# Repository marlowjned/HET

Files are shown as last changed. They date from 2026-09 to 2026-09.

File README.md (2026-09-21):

# HET — Hall Effect Thruster simulation

Simulating the magnetic circuit (and eventually more) of the BPL-700 Hall
Effect Thruster, from first-pass sizing through real-CAD magnetostatic FEM
solves. Two independent geometry/FEM toolchains exist side by side because
the first one (MATLAB) hit a real geometry-kernel limitation partway
through; rather than being redundant, the second (Gmsh+GetDP) is the one
that's currently ahead and validated. This file is a map of the repo, not a
status report — each subfolder's own README/notes carry current status.

Material properties used anywhere in the project, with sources and a
per-value confidence rating, are collected in **`MATERIALS.md`**.

## Layout

- **`sizing/`** — `basic_het_sizing.py`: zero-CAD, textbook top-level
  sizing (Goebel & Katz scaling laws) — discharge current, channel
  geometry, thrust/Isp/efficiency, and a Larmor-radius magnetization
  check, from power/voltage targets. Upstream of everything else: this is
  where target channel dimensions and required B-field would come from if
  a new design point is needed, rather than the current placeholder
  numbers used downstream.
- **`matlab/`** — first magnetostatics pipeline: idealized parametric
  coil model (working), plus a real-CAD (Onshape STEP) import and
  placement pipeline (working). Blocked partway through multi-material
  assignment by a `fegeometry.union()` limitation on 5 of 9 real
  part-to-part interfaces (sliver/degenerate faces) — see
  `matlab/README.md` for the full diagnosis. Still the source of the real
  per-part transforms and material list used by the other pipeline.
- **`gmsh_getdp/`** — second, independent magnetostatics pipeline (Gmsh
  for geometry/meshing, GetDP for the FEM solve, both compiled native
  code) built specifically because it doesn't hit MATLAB's union
  blocker. Currently the most complete part of the project: validated
  against an analytic solenoid check, solves the full real assembly,
  and has run a center/outer current-ratio sweep. See
  `gmsh_getdp/README.md` for status/results and `gmsh_getdp/HOW_IT_WORKS.md`
  for the physics-to-code walkthrough (read that one to understand *why*
  any given step exists, not just what it does).
- **`thermal/`** — steady-state thermal model of the magnet circuit
  running on its own (coil dissipation only, no plasma load), in
  vacuum with radiation as the only heat path. Takes its radiating
  envelope from the `gmsh_getdp/` mesh and its winding design from
  that pipeline's operating point. Answers the "is anything getting
  hot before we add any other physics" question: no, with ~3x current
  margin to the first material limit. See `thermal/README.md`.
- **`tools/`** — gitignored, machine-local third-party binaries (the
  Windows GetDP executable). Not checked in; see `gmsh_getdp/README.md`
  "Setup" for how to repopulate it on a new machine.
- **`onshape/`** — HMAC API-key auth layer + caching STEP pull for a
  parametrized Onshape CAD document, keyed on all 5 real Configuration
  parameters (`emag_height`, `inner/outer_coil_id/od`). Auth and the
  multi-param STEP export are both validated end-to-end and wired
  directly into `gmsh_getdp/assembly/build_assembly.py`'s geometry
  ingestion. See `onshape/README.md`.

## How the pieces fit together

`sizing/` → target channel geometry and B-field (not yet actually wired
into the CAD dimensions below — the CAD is the existing real BPL-700
hardware, not a from-scratch design derived from this script). CAD
geometry now comes directly from a whole-assembly Onshape STEP export
(`onshape/cache.py` → `gmsh_getdp/assembly/build_assembly.py`), which
recovers Onshape's own real per-occurrence placement and part names
directly — the `matlab/` pipeline's hand-extracted per-part transforms
are no longer used by `gmsh_getdp/`. Material list (which parts are iron
vs. inert) originates in `matlab/README.md`'s diagnosis but is
re-confirmed against the real STEP body names in
`gmsh_getdp/assembly/build_assembly.py`. From here, active development is
in `gmsh_getdp/` — `matlab/` is not being advanced further unless the
union blocker gets resolved on the Onshape side.

## Current overall status

- Real-geometry magnetostatic B-field solve: **working**, in
  `gmsh_getdp/assembly/`, sourced from a parametrized whole-assembly
  Onshape STEP export (all 5 geometry params) rather than a fixed
  hardcoded geometry. Nonlinear iron (ASTM A36, modelled with an AISI 1008 proxy B-H curve,
  replacing the old linear `mur_iron=1000` placeholder) is implemented
  and **converging** — see `gmsh_getdp/README.md` "Nonlinear iron
  (B-H curve)". Winding excitation is no longer a placeholder: it's a
  real winding design (260/165 turns at 1.30 A) sized to the ~300 G
  channel-exit target, which is also what made the nonlinear solve
  tractable, since the old 5 A placeholder drove the iron past
  saturation. The magnet circuit needs ~3.8 V at 1.30 A, ~5.8 W.
- Top-level thruster sizing (power/thrust/Isp from design targets):
  **working**, standalone, in `sizing/`.
- Magnets-only thermal: **working**, in `thermal/` — 64 °C at the
  design point, first material limit (wire insulation) at ~2.4× design
  current. Plasma-loaded thermal is not modelled.
- Spacer-height geometry sweep: **done** —
  `gmsh_getdp/assembly/emag_sweep.py` drives Onshape → mesh → linear
  solve across `emag_height` (spacer 0–0.875 in) × inner core diameter;
  `sizing/winding_design.py` turns each result into a winding, current,
  voltage, power and temperature. Write-up with figures, every coil
  geometry and the power-supply requirements:
  **`EMAG_REPORT.pdf`** (rebuild with
  `python report/make_report.py`, which writes `EMAG_REPORT.pdf`).
- Not yet started: wiring `sizing/`'s targets into the CAD dimensions,
  electric-field/plasma simulation, electron
  trajectory/stability, plasma-loaded thermal, and structural/force
  analysis.

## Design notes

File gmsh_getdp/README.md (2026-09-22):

# HET B-field simulation: Gmsh + GetDP pipeline

A second, independent magnetostatics pipeline for the same BPL-700
geometry as `../matlab/`, built after MATLAB's `fegeometry.union()` proved
unable to cleanly union 5 of the assembly's 9 real touching interfaces
(sliver faces, unmeshable at any resolution -- see `../matlab/README.md`,
"Blocker hit at step 1"). Both mesh generation (Gmsh) and the FEM
assembly/solve (GetDP) are compiled native code -- Python here is only
orchestration (build geometry, write the mesh, shell out to `getdp.exe`,
read results back), not the numerical engine.

## Status

- **Toy validation**: done and passing. `toy_test/` builds a single
  parametric solenoid coil (same dimensions as
  `../matlab/het_solenoid_bfield.m`'s center coil) and solves it with
  GetDP's magnetic-vector-potential formulation. Result: 27.63 mT on-axis
  at coil center, vs. 28.02 mT from the exact analytic on-axis integral
  for a finite thick solenoid (1.4% agreement) -- confirms the mesh,
  formulation, and gauge are all correct before trusting them on the real
  CAD. Run `python check_toy.py` after the solve: it asserts the
  comparison rather than leaving it as a number quoted here, which is what
  let a real error hide for months -- see "The A_cross bug" below.
- **Real assembly**: done and solving, now sourced from a **whole-assembly
  Onshape STEP export** (via `../onshape/cache.py`) rather than the
  original per-part-STEP + hardcoded-transform approach. `assembly/
  build_assembly.py` imports all 14 named bodies directly (7 iron + 5 real
  coil solids + chamber + chamber_spacer), fuses the iron bodies
  **incrementally** into one solid, keeps the 5 coil solids as real
  windings (no more `occ.addCylinder`/`occ.cut` primitive construction),
  meshes, and solves. **All real touching interfaces mesh cleanly** (vs.
  MATLAB's 4/9) -- see "The geometry win" below. All 5 real Onshape
  Configuration parameters (`emag_height`, `inner/outer_coil_id/od`) now
  drive this pull -- see `../onshape/cache.py`'s docstring for why (the
  soft-iron core's diameter IS the coil ID it wraps, so there's no
  separate core-diameter parameter). `chamber_spacer` is iron (confirmed
  2026-09-21: the same A36 as the plates; `--exclude-chamber-spacer`
  still tests the inert case).
- **Center/outer current-ratio sweep**: done at the old geometry and the
  old linear-iron material (pole names `center_solenoid`/`outer_solenoid`,
  since renamed to `inner_coil`/`outer_coil` -- `current_sweep.py` itself
  is updated for the rename, but hasn't been re-run against the new
  whole-assembly geometry, and its channel statistics predate the ROI
  correction below). Found the most radial (E x B - correct) channel
  field at `I_center = I_outer` -- see "Current ratio sweep" below. **Its
  2-basis-solve superposition trick assumes a linear material**, which
  looked fatal once Iron became nonlinear -- but at the real ~300 G design
  point the iron peaks at 1.023 T, below the B-H knee, so it behaves
  near-linearly and the trick is roughly valid there. Note this got
  *weaker* when the material became A36-proxy rather than the old generic
  curve: 1.023 T is past that curve's peak-permeability point (0.865 T),
  so superposition is now an approximation rather than near-exact.
  Re-check it if a design point pushes the iron further.
- **Materials**: nonlinear iron (ASTM A36, run on a proxy B-H curve) replaces
  the `mur_iron = 1000` linear placeholder, and **converges** -- 33
  Picard iterations, 68 min wall, 806 MB peak. See "Nonlinear iron
  (B-H curve)" below for how the excitation, not the method, was what
  made that work. The iteration count roughly tripled when the material
  went from the generic curve to the A36 proxy: the design's peak iron
  field sits past that curve's permeability peak, where Picard contracts
  slowly. Worth budgeting for in the geometry sweep.
- **Excitation**: 1.30 A per coil (inner 260 t, outer 165 t) -- a real
  winding design sized to the ~300 G channel-exit target, not the old
  inherited 300/200 at 5 A. Measured 288.6 G at the exit plane at 1.25 A,
  hence 1.30 A for 300 G. See "Operating point" below.
- **Channel ROI**: the channel bounds in `assembly_params.txt` are the
  real plasma cavity between the chamber's ceramic walls, not the chamber
  part's bounding annulus (which contained iron). See "Channel ROI" below.
- **chamber**: deliberately excluded from the solid model (see
  `assembly/build_assembly.py` docstring) -- magnetically inert (mu_r ~=
  1, same as air), so omitting it doesn't affect the B-field solve.
  **injector** isn't present in the whole-assembly STEP export at all
  (confirmed) -- harmless, it was already excluded for the same reason.

## Setup

```
pip install gmsh meshio pyvista        # geometry/meshing API, VTK export, VTK-based slicing (all C++ core underneath)
# GetDP: download the Windows binary from https://getdp.info/ (bin/Windows/getdp-3.5.0-Windows64c.zip)
# and unzip it -- this repo expects it at ../tools/getdp-3.5.0-Windows64/getdp.exe
# (../tools/ is gitignored; not checked in)
```

## Running

```
cd toy_test
python build_toy.py
"../../tools/getdp-3.5.0-Windows64/getdp.exe" magnetostatics_toy.pro -msh toy.msh -solve Res_a -pos Map_b
python check_toy.py                             # asserts the FEM against the exact analytic field; exits non-zero on failure

cd ../assembly
python build_assembly.py                       # writes assembly.msh + assembly_regions_generated.pro + assembly_params.txt
"../../tools/getdp-3.5.0-Windows64/getdp.exe" magnetostatics_assembly.pro -msh assembly.msh -solve Res_a -pos Map_b
python post_process.py                          # writes solve_summary.txt + cross_section.png (quick static check)
python export_vtk.py                             # writes assembly_field.vtu + iron_field.vtu (standard VTK) -- run before the viewer below
python cross_section_viewer.py                  # interactive angle-sweep viewer (opens a window), reads assembly_field.vtu
```

## The geometry win

MATLAB's `union()` broke on 5 of 9 real touching interfaces: all 3 of
chamber's contacts (hard failure, degenerate triangles) and 2 of the 4
outer-pole-to-top-plate mates (sliver faces, unmeshable). Gmsh/OCC's
fuzzy-tolerance boolean kernel (`Geometry.ToleranceBoolean`) fused all 7
real iron parts (top plate, bottom plate, center pole, 4 outer poles) into
a single solid **on the first try**, including the exact
outer_solenoid_2/_7 <-> top_plate mates that broke MATLAB. This is the
main validation that switching toolchains actually fixes the root
problem, not just relocates it.

## Result file formats

- **`assembly.msh`** -- the mesh (nodes, elements, physical-group region
  tags). Gmsh legacy ASCII v2.2. No field data.
- **`b_assembly.pos`, `b_iron.pos`** -- GetDP's native output (Gmsh's
  `.pos` ASCII post-processing view format): one `VS(...){...}` line per
  tetrahedron, its 4 corner coordinates and constant field value. Plain
  text, large (~200MB for the full assembly).
- **`assembly_field.vtu`, `iron_field.vtu`** (`export_vtk.py`) -- the same
  field data as standard VTK (XML/binary, `UnstructuredGrid`), for
  ParaView or any other VTK-standard consumer -- the interoperable format
  if this ever gets layered against other simulation tools. Built via
  `meshio` directly from the `.pos` element data (each tet keeps its own
  4 corner points rather than being deduplicated against a shared mesh --
  see `export_vtk.py`'s docstring for why: **`gmsh.view.write(tag,
  "*.vtk")` looked like it worked (no error) but silently wrote a
  non-standard format** -- no `# vtk DataFile` header, none of the
  expected `POINTS`/`CELLS` sections -- so don't reach for it as a
  shortcut here). Verified by a full round-trip read: peak `|B|` in the
  `.vtu` matches the known `.pos` value (9.671343399912887 T) exactly.
- `post_process.py` still reads `.pos` directly via `pos_utils.py` (its
  own quick static check, unchanged). `cross_section_viewer.py` now reads
  `assembly_field.vtu` via `pyvista` instead -- see "Known limitations"
  below for why that's a real accuracy improvement, not just a format
  swap, and note it means `export_vtk.py` must be run before the viewer.

## Current ratio sweep

`assembly/current_sweep.py` sweeps the center-solenoid / outer-solenoid
current ratio and finds which one makes the discharge-channel field most
radial (perpendicular to the thruster centerline) -- the standard Hall
thruster requirement for E x B electron confinement.

**Key physics shortcut**: with the linear `mur_iron = 1000` placeholder
(no B-H saturation), the magnetostatics problem is linear in the winding
currents, so solutions superpose. The script solves GetDP only twice --
once with 1 A in the center winding alone, once with 1 A in each outer
winding alone -- caches both per-element channel fields to
`channel_basis.npz`, then evaluates `B(x) = I_center * B_center_unit(x) +
I_outer * B_outer_unit(x)` for any current pair instantly in Python (no
remeshing or re-solving). Use `--skip-solve` to re-sweep or re-plot from
the cached basis without paying for the two GetDP solves again.

**Result** (`sweep_results.csv`, `sweep_ratio.png`; 25 ratios from 0.4 to
2.5, `I_outer` fixed at the reference 5 A/coil): the channel field is most
radial -- lowest volume-weighted axial fraction, `mean(|B_y|/|B|) =
0.4848` -- at **`I_center / I_outer = 1.0`**, i.e. equal current in the
center and each outer coil (`I_center = I_outer = 5 A`). This happens to
coincide with the placeholder excitation already used for the base solve
(`center 300t/5A, outer 200t/5A`) -- not by design, since the turns
differ 300 vs. 200 per coil, but the ratio metric is fairly flat near its
minimum (axial fraction only rises from 0.485 to ~0.54 across the whole
swept range), so this isn't a sharp optimum. At that point:

- channel `|B|` mean = 80.6 mT, median = 8.5 mT, p90 = 33.3 mT (the mean
  is pulled up by a small high-field volume near the pole faces; the
  median is more representative of the bulk channel field).
- to hit a different target channel field while keeping the field
  direction optimal, scale **both** currents together by
  `target / 80.6 mT`, keeping the 1:1 ratio fixed.

**Those three magnitude numbers are stale** -- they were computed with
the old channel mask (the chamber part's bounding annulus, which
included iron; see "Channel ROI" above), so they average pole-face field
into the channel and the spread between mean/median/p90 is largely that
contamination rather than real structure. Over the corrected plasma
cavity the field is far more uniform and almost purely radial (97.7%).
The *ratio* result is unaffected -- that metric is scale-invariant and
the contamination was symmetric across ratios -- but don't use the mT
figures above to size current; use "Operating point" instead.

This is a field-direction optimum only -- it says nothing about the
field *magnitude* needed for a real operating point (that depends on
electron Larmor radius / discharge voltage requirements, not modeled
here), and the underlying solve is the linear/no-saturation placeholder
-- though see "Nonlinear iron" above for why superposition turns out to
be legitimate at the real design point anyway.

## Spacer-height sweep (`emag_sweep.py`)

Sizes the `chamber_spacer`. Full write-up, figures and every coil geometry:
**`../EMAG_REPORT.pdf`**. Geometry facts it rests on,
measured from the STEP exports:

- **spacer = emag_height - 1.125 in.** The chamber and top plate never
  move; emag_height moves only the bottom plate. At 1.125 in Onshape drops
  the spacer body entirely (`build_assembly.py` accepts that).
- The chamber bore and spacer bore are both the inner coil's OD
  (r 17.46 mm), so the inner winding can only grow inward by thinning the
  core (`inner_coil_id`). The pole cap stays 1.375 in regardless.

Grid: emag_height 1.125-2.0 in (spacer 0-0.875 in, 0.125 steps) x inner
core 1.000/0.875/0.750 in, plus one outer-OD 1.625 in check -- 25 points.
**Linear iron** (mu_r 1500): +1.25% on exit field vs the committed nonlinear
solve at equal current (`--validate`), ~2.5 min/point instead of ~70.

Results (`assembly/emag_sweep_results.csv`), all scaled to 300 G at the exit:

- A-turns for 300 G: inner 326-339, outer 207-215 each, across the whole
  grid. Spacer height moves it ~1% (= mesh noise); a 0.750 in core adds ~2%.
- Core shaft flux 0.34-0.74 T, highest at the **longest** spacer (the steel
  spacer wraps the inner coil and pulls leakage flux through the core).
  Knee on the measured 1020 curve is 1.3-1.5 T.
- The spacer mostly changes winding room: AWG 20 at the 1.000 in core goes
  1.27 A / 5.1 W (spacer 0.875) -> 2.25 A / 10.0 W (spacer 0). A 0.750 in
  core with no spacer is 1.28 A / 5.4 W -- today's numbers.

Worst-case nonlinear check (`--nonlinear h2.000_ci0.750_oo1.500`, 0.74 T
core): the 50% stage converged in 9 Picard iterations, but the 100% stage
**stalled** at rel. residual ~0.11 for all 60 iterations (2.4 h) -- not
converged. Unconverged, it matches linear to 0.3% at the exit and puts the
inner core 3.4% lower; its p99.9 iron |B| is 13% higher (a few corner
elements, plausibly where Picard stalls).

**Fine ramp tried (`--fine-ramp`, 9 stages 0.5..1.0), also terminated.**
Stages converged at 50% (9 iterations), 60% (16) and 70% (35), but Picard
contraction fell stage by stage (~2.3x -> 1.7x -> 1.2x per iteration), and
at 75% it dropped to ~1.1x (rel 9.9e-3 at iteration 13), projecting past the
60-iteration cap. Meanwhile getdp.exe grew to 13 GB resident (vs ~0.8 GB for
a 2-stage solve) and slowed to >3 min/iteration -- the repeated
Generate/Solve memory growth noted under "Nonlinear iron". Killed per the
watchdog criteria (`nl_watchdog.py`). Nothing is saved from the converged
stages because `SaveSolution` only runs at the end. So a finer ramp is not
the fix; Newton (with the `dhdb[]` tangent) is the remaining option, and
saving a solution per stage would make a partial run worth something.

Two pipeline fixes came out of it: `build_assembly.py`'s mesh fine size is
now capped at the baseline value (a thinner core coarsened the whole mesh,
which failed on the bottom plate's 2 mm lead holes and made resolution vary
across the sweep), and a meshing exception now finalizes gmsh (leaving it
initialized made the *next* build silently write an empty mesh).

## Operating point

Target: **~300 G radially at the channel exit**, tapering toward the
anode (the magnetic-lens shape `assembly/field_quality.py` scores
against). The design point that meets it is **338 A-turns on the inner
pole and 215 on each outer pole** -- realized as 260 / 165 turns at
1.30 A, wired in series.

Two independent derivations agree:

- **Lumped reluctance**: 300 G in air needs H = 23.9 kA/m; across the
  37.4mm inner-core-to-outer-core air path that's ~450-900 A-turns
  depending on how much of the path holds full field. The iron leg
  contributes ~2.5 A-turns (227mm at ~0.1 T), i.e. nothing -- this is a
  gap-dominated circuit.
- **The solve itself** (A36-proxy iron): 288.6 G at the exit plane at
  1.25 A, peaking at 308.5 G about 3.5mm inboard of it. Scaling to 300 G
  gives 1.30 A. Note the iron is no longer strictly linear at this point,
  so that scaling is slightly optimistic.

For contrast, the original placeholder was 5 A at 300/200 turns,
inherited from `../matlab/het_solenoid_bfield.m`'s parametric check and
never derived from a target. That is ~3x the required A-turns, and is
what drove the iron past saturation and made the nonlinear solve
intractable (see "Nonlinear iron" above).

## Solenoid winding design

Only the **A-turn product** reaches the FEM (as a bulk current density,
see HOW_IT_WORKS.md sec. 2), so the wire choice below changes the
current/voltage split and nothing about the field. Every row delivers the
same 325/206 A-turns and therefore the same 300 G.

Windows measured from the real CAD coil solids: **4.76 x 50.8 mm**
(inner) and **6.35 x 50.8 mm** (outer); mean turn lengths 94.8 and
99.7 mm. Turn counts assume fiberglass-served wire, hexagonally nested,
with the inner coil wound full and the outer coils wound to 0.63x that so
one series current gives the 1.58 A-turn ratio the field wants.

| AWG | N inner | N outer | layers in/out | current | V @ 20 C | V @ 60 C | total P |
|---|---|---|---|---|---|---|---|
| 16 | 105 | 67 | 3 / 2 | 3.10 A | 1.46 V | 1.69 V | 5.2 W |
| 18 | 172 | 109 | 4 / 3 | 1.89 A | 2.30 V | 2.67 V | 5.0 W |
| **20** | **260** | **165** | **5 / 4** | **1.30 A** | **3.81 V** | **4.42 V** | **5.8 W** |
| 22 | 384 | 244 | 6 / 4 | 0.85 A | 5.84 V | 6.76 V | 5.7 W |
| 24 | 624 | 396 | 8 / 6 | 0.52 A | 9.26 V | 10.72 V | 5.6 W |

AWG 20 is what `build_assembly.py`'s `EXCITATION` is set to. Switching
rows needs no re-solve -- just the turns/current pair.

**Dissipation is ~5 W in every row**, which is the useful structural
result here:

```
P = (N*I)^2 * rho * L_turn / (k * A_window)
```

Wire gauge cancels: thinner wire raises resistance exactly as fast as the
lower current reduces I^2. The only levers on heat are window area,
packing factor, turn length, and the A-turn requirement itself. Choosing
a gauge is a power-supply matching decision, not a thermal one.

Conductor current density is 2.4-2.7 A/mm^2 across the table --
comfortable even with vacuum/radiation-only cooling. A standalone
radiation balance (all 5 W leaving a ~0.070 m^2 envelope by radiation
alone, no conduction path) puts the assembly at roughly 42-60 C depending
on surface emissivity, so the magnet circuit is not thermally
interesting on its own.

**Soft inputs**: the insulated-diameter figures are representative of
single glass serving rather than taken from a datasheet, and they set the
turn counts -- a real wire spec could move N by 10-20%, which moves the
current, not the field or the power. Wiring in series is what forces
equal current through coils of unequal resistance; running the coils at
different currents needs two supplies or a trim resistor on one leg.

## Iron material data (ASTM A36)

The poles and plates are ASTM A36, from SendCutSend hot-rolled
pickled-and-oiled stock -- their 1008 cold rolled tops out at 0.135 in,
too thin for anything here, and A36 is stocked at exactly the 0.375 in
plate thickness. See `../MATERIALS.md` for the full property table and
sourcing. Magnetic data is a 19-point DC
magnetization curve inline in `assembly/generate_regions.py`; thermal and
physical properties are in `../thermal/radiation_balance.py`.

| property | value | use |
|---|---|---|
| saturation (B at 1000 Oe) | 2.165 T | magnetics (proxy curve) |
| peak relative permeability | 2164, at H = 318 A/m | magnetics (proxy curve) |
| mu_r at this design's peak iron field | ~1935 at 1.023 T | magnetics (proxy curve) |
| thermal conductivity | 50 W/m-K | justifies the isothermal-iron assumption |
| specific heat | 470 J/kg-K | transient model, when one exists |
| density | 7900 kg/m^3 | as above |
| max service temperature | 400 C | thermal limit |
| Curie point | ~770 C | magnetic circuit fails well before this |

**Read the provenance before trusting the magnetic curve.** It is **AISI
1008 data used as a proxy for A36**, deliberately not relabelled -- no
numeric A36 table could be obtained. The 1008 points themselves come from
the Ansys Maxwell SV material library, transcribed via a public
engineering forum; the primary source could not be re-fetched (403).
Neither a measurement of A36 nor of the actual BPL-700 stock.

A36 carries up to 0.26% carbon against 1008's ~0.08% plus up to 1.2% Mn,
so **real A36 is less permeable than this curve and the model is
optimistic about the iron** -- plausibly a few percent of channel field,
i.e. a design current nearer 1.35 A. See `../MATERIALS.md`.

What supports them being genuine digitized data: every H value is an exact
Oersted multiple (2, 4, 6, 8, 10, 20, 40 ... 5000 Oe), which is how
pre-SI magnetization tables were published; the curve is monotonic in both
variables; differential permeability rises then falls as a real
magnetization curve must; and 2.165 T at 1000 Oe sits squarely in the
2.1-2.2 T band expected of low-carbon steel.

What should keep you cautious:

- **1008 is not an electrical steel.** ASTM imposes no magnetic
  requirement on it at all, so two suppliers' 1008 can differ
  substantially and nothing obliges either to match this curve.
- **Processing history dominates.** Peak mu_r of 2164 is characteristic of
  as-rolled rather than annealed material; annealed low-carbon steel
  reaches 3000-5000. If the real poles are annealed they will outperform
  this model slightly.

Fortunately this matters less here than it would in most magnetic designs,
because the circuit is gap-dominated: the iron carries ~2.5 of the ~900
A-turns. Switching from the old generic curve to 1008 cut permeability at
the operating point by 2.7x (mu_r 5700 -> 2150) and moved the channel
field by well under a percent. A measured curve on the actual stock is
still the only way to do better, but it would buy very little.

## The A_cross bug (fixed 2026-09-19, worth knowing about)

Both `build_assembly.py` and `build_toy.py` computed the winding's
current-density area as the **annulus**, `pi*(ro^2 - ri^2)`. The current
is azimuthal, so it crosses a plane *containing* the axis: the correct
area is the coil's r-z section (radial thickness x height). The annulus
is the area for *axial* flow, and it is 1.84x (inner) / 1.94x (outer) too
large here, so every solve silently applied about half its nameplate
A-turns. The toy case was 2.75x off.

**The toy validation could not catch it**, because `build_toy.py` fed the
same wrong area into both the FEM source term and its analytic reference.
The two agreed to 1.4% at 10.19 mT while the true answer was 28.02 mT --
a comparison that cannot fail is not a validation. That is why
`check_toy.py` now exists and asserts, and why `A_cross` is derived via
Pappus's theorem (`A = V / 2*pi*r_mean`) from the solid's own volume
rather than from nominal dimensions.

Second-order lesson from the same fix: `magnetostatics_toy.pro` held a
hand-copied `Jmag` literal, so the first corrected re-solve silently
reused the old value. It now `Include`s a file `build_toy.py` generates,
matching how the assembly pipeline already worked.

Everything *shape*-based from before the fix survived it -- the ROI work,
the lens profile, radial purity, the saturation conclusion -- because a
scalar error in J rescales the field without changing its geometry. What
changed is the label on the current axis.

## Channel ROI

The channel bounds in `assembly_params.txt` (`channel_inner_r`,
`channel_outer_r`, `channel_y_anode`, `channel_y_exit`) define the **real
plasma cavity** -- the open annulus between the chamber liner's ceramic
walls. Confirmed against the CAD: ID 1.74 in, OD 2.5 in, 1.375 in axial
span, exit at y = -1.25 in, anode end at y = +0.125 in.

This used to be the chamber *part's* bounding annulus (r 17.30-41.44mm,
y -32.51..+5.59mm) -- i.e. the whole ceramic liner including both walls.
That is not the plasma channel, and it mattered: that box contained 5392
iron elements at the exit end, so channel field statistics were averaging
in pole-face material. Correcting it moved radial purity from 82.5% to
97.7% and removed a spurious 2.2x jump between adjacent axial stations.

`detect_channel_cavity()` in `build_assembly.py` finds the cavity from
the chamber geometry so this survives a geometry sweep. Two traps it
documents, both hit while building it:

- It needs chamber **volume** element centroids, not surface nodes. A
  surface mesh puts no points inside solid material, so a wall's interior
  reads identically to open space -- with surface nodes it confidently
  returned the outer wall's guts (r 31.98-40.94mm) as the "cavity".
- The detected band must be trimmed clear of the wall faces before
  locating the closed end, or a fraction of a bin of wall overlap reads
  as material at every y and collapses the channel to 0.01mm long.

**Known gap**: the detector lands ~0.76mm off the CAD-confirmed bounds
(it reads centroids, which sit half an element inside the true faces), so
re-running `build_assembly.py` will overwrite hand-confirmed values with
slightly shifted ones. Either snap its output to the nearest real chamber
face or take the channel dimensions as explicit parameters.

## Whole-assembly STEP import (now the live pipeline)

`assembly/scratch_whole_assembly_import.py` was the spike that validated
this; `build_assembly.py` now uses it for real, replacing the old
per-part-STEP-export + hardcoded-placement-table pipeline entirely
(`TRANSFORMS`, ported from `matlab/new_export/apply_transforms.m`, is
gone). Findings that carried over from the spike into the real pipeline:

- Gmsh/OCC recovers Onshape's own real per-occurrence placement exactly
  and preserves part names as entity labels -- no manual per-file
  transform bookkeeping needed. Confirmed body names (2026-09-18 pull):
  `top_plate`, `bottom_plate`, `inner_emag_core`, `outer_emag_core` (x4)
  -- iron; `inner_coil`, `outer_coil` (x4) -- real winding solids;
  `chamber`, `chamber_spacer`.
- Fusing all iron parts in **one batch call** only produced 3 disjoint
  solids on this file, not 1 -- OCC's fuzzy boolean union is
  order/grouping-dependent (same non-symmetry already noted in
  `../matlab/README.md` for MATLAB's kernel). Fusing **incrementally**
  (one part folded into the growing result at a time) gives the correct
  single solid, and is what `build_assembly.py` does now.
- The usual mm-labeled-as-m unit bug is present in this STEP too --
  `build_assembly.py` applies the `0.001` scale to all imported solids at
  once, right after import (before any boolean op), which the spike found
  more reliable than scaling pre-placed per-part templates.
- **New gotcha found wiring this in for real** (not seen in the spike,
  which only checked placement, not areas/volumes): `occ.getBoundingBox()`
  returns a **loose/conservative box on curved STEP-imported solids** --
  e.g. a coil's true X/Z extent (confirmed via actual mesh nodes) equals
  its OD on both axes, but `getBoundingBox()` reports the right value on
  one axis and up to ~1.75x too large on the other, for the *same* solid,
  reproducible with no boolean ops involved at all. Only the axis bounded
  by curved (not flat end-cap) surface is affected. `build_assembly.py`
  no longer uses `getBoundingBox()` for anything needing X/Z precision on
  these bodies -- `getMass()`/`getCenterOfMass()` (volume integrals over
  the true trimmed solid, not boundary-based) are trustworthy and used
  instead.

## Nonlinear iron (B-H curve) -- converged

Replaced the `mur_iron = 1000` linear placeholder with a real saturating
B-H curve, since the linear solve was reporting unphysical peak |B|
(9.7 T under the old geometry, 2.16 T under the new whole-assembly
geometry at the old placeholder excitation -- both well past where
real soft iron saturates, ~1.5-2 T).

**The short version of everything below**: two attempts at this failed
while the excitation was still the inherited 5 A placeholder, and the
fix turned out not to be a better nonlinear method but a correct
operating point. At 5 A the poles are driven to 2.16 T, past the B-H
knee, and no amount of load-stepping made that cheap. At the real
~300 G design current (1.30 A, 338/215 A-turns) peak iron is 1.023 T,
the material is effectively linear, and the solve converges in 12 Picard
iterations / 28 min / 806 MB with a 2-stage ramp. The debugging history below is
kept because the failure modes are informative, not because the
16-stage ramp is still needed.

- **Material**: **ASTM A36**, modelled with a 19-point AISI 1008 proxy H/B table inline in
  `generate_regions.py`. This replaced GetDP's bundled generic
  `SteelGeneric` dataset, which was a stand-in from when the pole material
  was unspecified. Reluctivity is built as a piecewise-linear
  interpolation of `H/B` vs `B^2`
  (`InterpolationLinear[SquNorm[$1]]{...}`, the derivation GetDP's own
  `Lib_Materials.pro` uses), assigned to `Iron` only -- `Air`/`Windings`
  stay linear. See "Iron material data" below for provenance and the
  caveats, which are real.
- **Formulation**: `magnetostatics_assembly.pro`'s single
  `nu[] * Dof{d a}` Galerkin term is now split into a linear part
  (`Air+Windings`) and a nonlinear (Picard) part over `Iron`
  (`nu[{d a}]`), evaluated at the previous iteration's field -- same
  `Vol_L_Mag`/`Vol_NL_Mag` split GetDP's own `Lib_Magnetostatics_a_phi.pro`
  template uses. Full Newton (with a `dhdb[]` tangent term) was the
  template's own default, but its exact tangent-derivative macro syntax
  (`SquDyadicProduct[#1]`-based) wasn't confidently reproducible without
  risking a silently-wrong-not-obviously-broken linearization, so Picard
  was chosen for v1 as the lower-risk option.
- **Plain Picard diverges from a cold start**: tried first, confirmed
  empirically -- residual dropped 613 -> 96 over 2 iterations, then
  exploded to 1.7e5 on the 3rd. Root cause: this B-H curve's slope gets
  extremely steep near saturation (H jumps from 3.1e5 to 7.6e5 A/m over
  the last few tenths of a Tesla), and the linear solve's own peak
  (2.16 T) starts the very first nonlinear iteration right in that steep
  region -- too large a jump for unrelaxed Picard to track.
- **Fix: load-stepping (continuation)**. Excitation is scaled by a
  runtime `$IFrac` (in `Js[]`, `generate_regions.py`), ramped up in
  stages from a small fraction to full current in
  `magnetostatics_assembly.pro`'s Resolution, Picard-converging fully at
  each stage before stepping up -- every stage continues from the
  previous stage's already-converged field (no `InitSolution` between
  stages), so each individual Picard step only tracks a small change
  instead of jumping from zero into saturation.
- **First attempt (8 uniform stages, `NL_iter_max=20`, `NL_tol_rel=1e-6`)
  ran to completion but did not converge.** Confirmed empirically
  (~97 min wall / ~10.3 CPU-hr): stages up to 37.5% converged cleanly (2,
  4, 9 iterations); the 50% stage was still improving *monotonically*
  every iteration (never oscillating) but hit the 20-iteration cap at rel.
  residual ~2e-3 -- genuinely converging, just under-budgeted, not
  diverging. Because that stage got cut off unconverged, the next stage
  (62.5%) inherited a not-quite-right field and started oscillating; by
  75-100% the residual was exploding 1-3 orders of magnitude per
  iteration. The saved (garbage) result had peak |B| = 6.5 T, confirming
  it wasn't a real solution. Root cause: iteration/tolerance budget, not
  an unreachable solution.
- **Second attempt: finer ramp (16 non-uniform stages, denser above 40%),
  `NL_iter_max=60`, `NL_tol_rel` relaxed to 1e-4.** This behaved much
  better -- stages 0-3 (10/20/30/40%) all converged cleanly and
  monotonically (2, 4, 6, 9 iterations respectively, well inside the new
  budget), no oscillation at all through 40% (vs. the first attempt's
  visible strain already building by 37.5%). **Killed by the harness at
  ~53 min in (partway into stage 4, 45%) due to host-level memory
  pressure** -- not a divergence or a bug in the solve itself. Both
  attempts showed the same pattern: `getdp.exe`'s resident memory
  oscillates (grows during a Generate/Solve/factorization, drops after)
  rather than climbing monotonically, but the *peaks* got large enough
  (workstation has 31 GB RAM; observed available-memory dips as low as
  ~4.5 GB on the second run) that the environment's own low-memory
  protection stepped in before stage 4 could finish. Likely cause:
  MUMPS's LU factorization data isn't being released between the many
  repeated `Generate[]`/`Solve[]` calls this manual iteration loop makes
  (16 stages x up to several iterations each, all against a 589k-DOF
  system) -- plausible but not root-caused.
- **Resolution: the excitation was wrong, not the solver.** Both failures
  above were chasing a saturation regime the design never called for. A
  lumped reluctance check against the 300 G channel target (see
  "Operating point" below) needs ~450-900 A-turns; 5 A was supplying
  2500. Dropping to the real design A-turns puts peak iron at 1.023 T -- below the knee,
  where this B-H curve is nearly straight -- and the same formulation,
  mesh and Picard iteration then converge easily:

  | | 5 A placeholder, 16 stages | design point, 2 stages |
  |---|---|---|
  | Picard iterations | hit caps, oscillated | 12 total, monotonic |
  | wall time | ~97 min / killed at 53 min | 28 min |
  | peak memory | host dipped to ~4.5 GB free | 806 MB |
  | peak iron \|B\| | 2.157 T (past knee) | 1.023 T |
  | result | garbage (6.5 T) / unfinished | converged, rel 9.9e-5 |

  Contraction was clean throughout: stage 0 converged in 3 iterations
  (48x/27x/23x per step), stage 1 in 9, never oscillating. The host
  memory pressure that killed the second attempt simply never arises with
  ~1/8th as many large factorizations.
- **A useful corollary**: on the old generic curve the nonlinear peak matched a
  linear-scaled prediction from the old `mur_iron=1000` run to 0.4%.
  That is not a coincidence -- this is a gap-dominated circuit (iron drop
  ~2.5 of ~900 A-turns), so the answer is insensitive to iron
  permeability as long as it's large. Practical consequence:
  superposition is valid at the design point, so `current_sweep.py`'s
  cheap 2-basis-solve sweep is trustworthy again.
- **If a future design point does need saturation**, restore a fine ramp
  (git history has the 16-stage schedule) and budget accordingly, or
  switch to full Newton with the `dhdb[]` tangent -- the Picard/
  load-stepping combination is genuinely slow there.

## Known limitations / next steps
- **chamber/injector geometry not in the solve.** Fine for magnetostatics
  (inert, mu_r ~= 1) but would need reintroducing -- with a real inflate/
  clearance-gap fix, not a knife-edge boolean cut -- for any future
  thermal or structural model where their exact shape matters.
- **The excitation is derived now; the 300 G target itself isn't.** Both
  the A-turns and the turns/current split come from the field requirement
  plus the real coil windows (see "Operating point" and "Solenoid winding
  design"). What has *not* been traced back to first principles is the
  300 G number -- `../sizing/basic_het_sizing.py` assumes 150 G for its
  magnetization check, and reconciling those two is open. The per-wire
  resistance/voltage/power figures also remain a hand-calc the FEM
  doesn't model, and rest on representative rather than datasheet
  insulated-wire diameters.
- **`cross_section_viewer.py` now cuts the mesh exactly**, via
  `pyvista`'s `mesh.slice()` on `assembly_field.vtu` -- a real plane-mesh
  intersection, not an approximation. An earlier version inverse-distance
  -weight-averaged the 4 nearest element centroids on a regular query
  grid (a stand-in for MATLAB's `interpolateMagneticFlux`); that's gone
  now. Since `B` is piecewise-constant per element (see `HOW_IT_WORKS.md`
  sec. 9), each slice triangle just shows its parent element's true flat
  value (`ax.tripcolor(..., facecolors=...)`), which is actually the
  physically correct thing to show, not merely more convenient. One minor
  cosmetic side effect of no longer smoothing: the quiver arrows are
  noisier in the near-zero-field air region, since real per-element
  values (including small numerical near-cancellation vectors right at
  source/material boundaries) are shown unsmoothed -- harmless, but
  visually busier than the old averaged version.
- **The vacuum/air region was never missing** -- `Air` already covers
  the whole non-iron, non-winding space (including the channel) and was
  always part of the solve and `b_assembly.pos`. It just didn't *look*
  present: the channel's real field (~5-32 mT at the design point) is
  one to two orders of magnitude weaker than the iron near the poles
  (0.86 T), so sharing one color scale made it look empty.
  `cross_section_viewer.py`'s "region of interest" checkbox fixes the
  *display*, not the physics: it crops to the channel box and rescales
  color to a log range fit to the channel's own local |B|, which is what
  actually reveals the field structure there. Both that viewer and
  `post_process.py` now take their full-view color ceiling from the
  loaded solve rather than a hardcoded constant -- the old fixed 3 T
  ceiling was sized for the 9.7 T linear era and renders the current
  0.86 T solve almost entirely black.
- **Mesh resolution is a single pass**, not refinement-checked -- no
  convergence study yet (compare a coarser/finer mesh's peak/median |B|).

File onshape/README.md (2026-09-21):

# Onshape API access

Auth layer + caching STEP-pull for scripting against the parametrized
BPL-700 CAD in Onshape (document `c41ea30140eac94bca56baf9`, workspace
`f9e3107b7398b0d9cf6622d0`, "BPL-700 Assembly" element
`82b7a1bc6b1233ce1a780568`) -- generating a real, correctly-assembled STEP
export for a given `emag_height` without going through the Onshape UI by
hand.

The assembly exposes 5 Configuration parameters: `emag_height`,
`inner_coil_id`, `inner_coil_od`, `outer_coil_id`, `outer_coil_od` --
confirmed via a live `GET .../configuration` call, not assumed. **All 5
are sent to Onshape on every pull** (via `get_step_for_config`, keyed on
the full 5-param dict). An earlier version of this module sent only
`emag_height` and left the 4 coil ID/OD params at their Onshape defaults,
on the assumption they were purely local resizes not worth an API call --
that assumption was wrong: Onshape models a real coil solid per winding
(`inner_coil`/`outer_coil` in the STEP export), and the coil ID params
also size the soft-iron core each coil wraps (there's no separate
core-diameter parameter -- the core IS sized by the coil ID it sits
inside). See `cache.py`'s docstring for the multi-param encoding details.

## Setup

1. Generate an API key pair at the
   [Onshape Developer Portal](https://dev-portal.onshape.com) (the secret
   is shown once -- copy both values immediately).
2. Copy `.env.example` (repo root) to `.env` and fill in the real
   access/secret key. `.env` is gitignored -- never commit it.
3. `pip install onshape-rest-api-client python-dotenv httpx` (httpx comes
   in as a transitive dependency of the first, but is used directly here).

```python
from onshape.client import get_client

with get_client() as client:
    resp = client.get("/users/sessioninfo")
    resp.raise_for_status()
    print(resp.json()["name"])
```

## Why a hand-written `auth.py` instead of the installed client library

`onshape-rest-api-client` (PyPI, OpenAPI-generated straight from Onshape's
own spec) only ships a Bearer-token `AuthenticatedClient` -- meant for
OAuth2 access tokens, not Onshape's access-key/secret-key **HMAC** scheme.
There's no built-in support for signing requests with an API key pair.
`auth.py`'s `OnshapeApiKeyAuth` is a plain `httpx.Auth` implementing that
signing, ported from Onshape's own reference sample
(`onshape-public/apikey`, `python/apikey/onshape.py`) to modern Python 3 --
fetched and read directly before writing this, not reconstructed from
memory.

`client.py` builds a plain `httpx.Client` with that auth attached, rather
than using `onshape_rest_api_client.Client`/`.request()` calls. Two
reasons, both hit while validating this:

- **Base URL must include `/api`.** The generated client's per-endpoint
  code requests relative paths like `/users/sessioninfo` (no `/api`
  prefix), so `ONSHAPE_BASE_URL` has to be `https://cad.onshape.com/api`,
  not just `https://cad.onshape.com` -- easy to get wrong once and see a
  confusing "Expecting value" JSON-decode error (the server serves an HTML
  page for the un-prefixed path, not JSON).
- **The generated response models have real bugs.** `session_info`'s
  typed model (`BTUserOAuth2SummaryInfo`) crashes deserializing a `null`
  nested `company` field (`TypeError: 'NoneType' object is not
  iterable`) -- confirmed the raw HTTP response was valid, correctly
  authenticated JSON; the crash is in the generated model's `from_dict`,
  not in this project's code. Given that, it's not worth taking on the
  generated client's model layer for every endpoint. The installed
  package is still useful as a **reference for exact endpoint paths and
  request shapes** (browse `onshape_rest_api_client/api/<tag>/<operation>.py`
  -- generated straight from Onshape's live spec) -- just parse responses
  as plain dicts via `response.json()` instead of the typed `.sync()`
  helpers.

## Getting a STEP export: `cache.py`

```python
from onshape.cache import get_step_for_height

step_path = get_step_for_height(1.5)  # emag_height, inches
```

Caches by `emag_height` in a local SQLite index
(`onshape/cad_cache/index.db`, gitignored along with the `.step` files
themselves -- large, regenerable, machine-local). A cache entry also
records the document's `sourceMicroversion` at fetch time; if the Onshape
document has been edited again since, the cached entry is treated as
stale and re-pulled automatically, so a mid-sweep CAD fix can't silently
leave old geometry in the cache. A cache hit costs one cheap
`get_configuration` read (to check the microversion) and no translation
call; a miss costs a translation request + poll + download (~10s here).

### Two non-obvious things that cost real debugging time getting here

- **The `configuration` parameter has to be a JSON body field on the
  right endpoint, not a query string.** `POST .../assemblies/d/{did}/w/
  {wid}/e/{eid}/export/step` (the dedicated "export as STEP" endpoint,
  and what the installed client's `create_assembly_export_step` wraps)
  silently **ignores** a `configuration` query parameter -- it exports at
  whatever the document's currently-saved configuration state is, no
  error, no warning. The one that actually honors it is the generic
  `POST .../assemblies/d/{did}/w/{wid}/e/{eid}/translations` endpoint
  (`translate_format` in the installed client), with `"configuration":
  "emag_height=1.5in"` (the `encodedId` form from
  `encodeConfigurationMap`, not the URL-encoded `queryParam` form) as a
  plain body field alongside `"formatName": "STEP"`. Confirmed against
  Onshape's own docs
  ([api-adv/configs](https://onshape-public.github.io/docs/api-adv/configs/))
  after silently getting the *default* geometry back twice.
- **`grouping: true` must be passed explicitly.** Without it (even though
  the installed client's stub documents `True` as the default), the
  export comes back as a **zip of flat, per-part STEP files at each
  part's own local origin** -- the same un-assembled, duplicate-position
  shape the old MATLAB pipeline had to work around with
  `apply_transforms.m` (see `../matlab/README.md`). With `grouping: true`,
  the result is one real STEP file with correct assembled placement
  (verified: the 4 `outer_emag_core` copies land at 4 distinct spread-out
  positions, not stacked on top of each other).

## Next

`get_step_for_config` and `gmsh_getdp/assembly/build_assembly.py` (whole-
assembly STEP import, real coil solids, incremental iron fuse) are wired
together and validated end-to-end with a real solve. Nonlinear iron is done,
and `gmsh_getdp/assembly/emag_sweep.py` is the first sweep driver built on
this cache (emag_height x inner_coil_id). At `emag_height=1.125in` the
spacer has zero height and Onshape omits the `chamber_spacer` body from the
export rather than erroring.

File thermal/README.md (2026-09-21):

# Thermal

Steady-state thermal model of the magnet circuit **running on its own** --
coil ohmic dissipation only, no plasma load. The question it answers is
"does anything get too hot just from energising the magnets, and at what
current does that change".

## Running

```
cd thermal
python radiation_balance.py
```

No arguments. It reads the radiating envelope from
`../gmsh_getdp/assembly/assembly.msh` if that exists (convex hull of the
iron and winding nodes) and falls back to a bounding cylinder otherwise,
so it runs standalone.

## Result at the design point

1.30 A, 260/165 turns of AWG 20 -- see `../gmsh_getdp/README.md`
"Solenoid winding design":

| | value |
|---|---|
| dissipation | 5.8 W |
| iron / PTFE | 64 C |
| coils, bonded to core | 65 C |
| coils, radiation-coupled only | 92 C |

Nothing is close to a limit. Margin to the first one:

| limit | | current | vs design |
|---|---|---|---|
| fiberglass wire insulation | 200 C | 3.09 A | 2.4x |
| PTFE chamber | 260 C | 3.76 A | 2.9x |
| ASTM A36 service limit | 400 C | 5.26 A | 4.0x |
| ASTM A36 Curie point | 770 C | 8.79 A | 6.8x |

The 200 C wire figure is deliberately conservative -- glass serving itself
tolerates far more, and the real limit depends on the binder. If that
number is firmed up, PTFE becomes the binding constraint.

Iron properties are ASTM A36 (k = 50 W/m-K, cp = 470 J/kg-K,
rho = 7900 kg/m^3, service 400 C, Curie ~770 C), from
[makeitfrom.com](https://www.makeitfrom.com/material-properties/ASTM-A36-SS400-S275-Structural-Carbon-Steel).
See `../MATERIALS.md` for sourcing and confidence.
Heat capacity and density are carried but unused by this steady-state
model -- they are what a transient warm-up version would need.

## What the model does and doesn't include

The thruster is assumed **radiatively isolated in vacuum**: no convection,
and no conduction path to a mount. Every watt therefore leaves by
radiation from the outer envelope, which makes the result a near-pure
radiation balance. If the real test fixture bolts the thruster to
something cold, this model is conservative.

Iron is treated as **one isothermal node**: conduction through it costs
~2 K at these power levels, far below the uncertainty in emissivity. The
coils are separate nodes because that interface is the only place a real
gradient forms -- in vacuum a coil that isn't bonded to the core can only
radiate across its gap, which is worth ~25 K.

**PTFE has no source term** in this configuration, so it floats at the
iron temperature. It still sets the current ceiling, because it has the
lowest limit in the build.

## The assumption that actually matters

**Envelope emissivity**, and it isn't close:

| eps | hottest part | surface |
|---|---|---|
| 0.15 | 98 C | polished steel |
| 0.30 | 65 C | bare machined steel (assumed) |
| 0.50 | 50 C | lightly oxidised |
| 0.80 | 42 C | blackened / anodised |

Sourced ranges (see `../MATERIALS.md`): mild steel is 0.20-0.32, so the
0.30 default sits at the *optimistic* end; real black coatings reach
0.88-0.91, better than the 0.80 used here.

That's a 56 C spread at the design current from one number, larger than
any geometric detail this model could resolve. Blackening the exterior is
the cheapest thermal margin available. If the real finish is unknown, read
the sweep rather than the single design-point figure.

## Not modelled

Plasma heat load to the channel walls and anode, which for a running
thruster is one to two orders of magnitude above the coil dissipation and
would dominate everything here. This model is deliberately the
magnets-only case; a plasma-loaded model needs the chamber in the domain
as a real heat-receiving body, and needs a heat flux distribution that
nothing in this repo currently produces.

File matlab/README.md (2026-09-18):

# HET B-field simulation

Goal: an accurate 3-D magnetostatic simulation of the BPL-700 Hall Effect
Thruster's magnetic circuit, using the real Onshape CAD geometry and
per-part material properties (relative permeability), solved in MATLAB's
PDE Toolbox.

## Status

- **Parametric solenoid model**: working (`het_solenoid_bfield.m`).
- **Real CAD geometry import**: working — see `new_export/`.
- **Material assignment**: not yet wired into a MATLAB solve. Materials
  are known (see below); the multi-domain classification pipeline that
  assigns them is prototyped in `new_export/scratch_classify.m`, but its
  first step (a clean `union` of iron + chamber + injector) hit a real
  geometry-kernel limitation. Re-diagnosed in detail since this was first
  written: it's not one bad interface, it's 5 of the assembly's 9 real
  touching interfaces (see "Blocker hit at step 1" under "Next step"),
  and the plan is being revised.
- **A second, independent pipeline outside MATLAB now exists and is
  further along**: `../gmsh_getdp/` (Gmsh for geometry/meshing, GetDP for
  the FEM solve — both compiled, not Python) fuses all 7 real iron parts
  cleanly on the first try (vs. MATLAB's 4/9 clean interfaces) and has a
  working, validated (1.4% vs. an exact analytic check) magnetostatic
  solve on the real assembly, including reasonable placeholder materials
  and winding currents. See `../gmsh_getdp/README.md` for status and
  caveats (still linear iron, no B-H saturation curve — same gap as here).

## Files

### `het_solenoid_bfield.m`
Preliminary magnetostatic model using idealized parametric geometry (no
CAD): one center-pole solenoid + four outer-pole solenoids spaced around
the discharge channel opening, driven at opposite polarity. No thruster
body/core material (relative permeability = 1 everywhere), so `|B|` here
is a topology/sanity check, not a final result. Includes an interactive
cross-section viewer. Confirms the field-generation pipeline (geometry,
`cellLoad` current density, boundary conditions, solve, visualization)
works before the real CAD geometry and materials are added.

### `new_export/` — real CAD geometry, correctly positioned
The current, working import of the actual BPL-700 assembly from Onshape:

- `BPL-700 Assembly - *.step` — one flat STEP file per named part
  (`chamber`, `injector`, `top_plate`, `bottom_plate`, `center_solenoid`,
  `outer_solenoid` x4). Each imports cleanly into `fegeometry` with no
  cleanup needed. These carry correct *shape* but not correct assembled
  *position* — Onshape's per-part STEP export flattens patterned
  instances to one local placement (see Gotchas below).
- `apply_transforms.m` — applies the real per-occurrence rotation +
  translation (extracted once from a whole-assembly STEP export,
  `BPL-700-assem-SIMS-V1.step` in the repo root) to each part above,
  producing correctly assembled geometry. Run this first; it writes
  `placed_parts.mat`. The transform values are hardcoded in this script;
  the one-time extraction script that produced them
  (`scratch_check_transforms.py`) has served its purpose and lives in
  `junk/` — only needed again if the assembly is re-exported with
  different placements.
- `placed_parts.mat` — output of `apply_transforms.m`: a cell array of
  9 correctly-positioned `fegeometry` objects (`placed`) with matching
  identity labels (`labels`, e.g. `outer_solenoid_1`).
- `check_placed.m` — loads `placed_parts.mat`, prints the overall
  assembly bounding box, and reports every pair of parts that touch or
  overlap (via `addCell` probing). Useful after any re-export to confirm
  the geometry still looks like a sane assembly.
- `scratch_center_gap.m` — one-off profiling of the chamber's radial bore
  vs. axial position in the center-pole's local frame. Confirmed the
  center pole is stepped: it's only "flush" against the chamber over the
  last ~11mm of its length (pole radius steps from 15.9mm to 30.8mm right
  there); across the other ~100mm the chamber's own bore stays at a
  constant ~30.6mm radius, leaving a genuine ~15mm annular gap around the
  thin pole section. That gap is the center winding's natural home — the
  chamber bore itself defines the winding OD, no invented wall thickness
  needed.
- `scratch_windings.m` — builds a hollow cylindrical winding-sleeve solid
  for each of the 5 poles (center + 4 outer), sized to fit the real
  clearance gap without touching iron/chamber/injector (the center one
  sized specifically to the thin-section gap found by
  `scratch_center_gap.m`), and verifies no winding-to-structure or
  winding-to-winding collisions. Geometry stage confirmed complete: all 5
  windings float freely with zero collisions. Writes `windings.mat`.
- `windings.mat` — output of `scratch_windings.m`: the 5 winding-sleeve
  `fegeometry` solids plus their labels/rotation/translation.
- `scratch_isolate_mesh.m`, `scratch_keepbound.m` — one-off checks that
  `union`-ing the iron/chamber/injector solids together stays meshable
  (incrementally, and with/without `KeepBoundaries`) before committing to
  the union-based multi-domain approach below.
- `scratch_classify.m` — first working prototype of the full multi-domain
  plan described in "Next step" below: unions iron + chamber + injector
  into one blob, adds the 5 windings as separate cells, meshes the whole
  9-cell geometry once, then classifies every element of the iron/chamber/
  injector blob into its correct region via `findCell` (with a
  nearest-solid fallback for elements it can't place directly). Prototype
  only — confirms the approach works on this geometry, but its output
  (`classified.mat`) isn't wired into a `femodel` solve yet and isn't
  checked into the repo.
- `scratch_pairwise_diagnose.m` — isolates every part pair that actually
  touches (rediscovers the contact graph itself via the same `addCell`
  probing `check_placed.m` uses) and unions just that pair alone, checking
  whether the resulting face count is exactly additive (clean shared
  boundary) or inflated (sliver faces), and whether the pair meshes at
  all. Localizes exactly which mating interfaces are broken instead of
  only knowing "the accumulated blob fails somewhere." See "Blocker hit at
  step 1" below for results.
- `scratch_check_tessellation.m` — checks each part's own STEP-derived
  boundary triangulation, independent of any union, for degenerate
  near-zero-area triangles. Distinct failure mode from the mating-pair
  check above: a part can be individually clean and still produce a bad
  union with a neighbor (a placement/tolerance problem), or be
  individually dirty regardless of who it's unioned with (an export-
  tessellation problem). See "Blocker hit at step 1" below for results.

### `het_view_assembly.m` (repo root)
Loads `placed_parts.mat` and renders all 9 parts together, color-coded by
part identity, with centroid labels, so the assembly can be rotated and
visually verified (correct part count, no stray duplicates, plausible
contacts, sane proportions) before trusting it for the solve. Confirmed
against the real geometry: two pole plates connected by 4 outer poles and
1 center pole, chamber nested in the middle.

### `BPL-700-assem-SIMS-V1.step` (repo root)
The whole-assembly STEP export used as the source of truth for real
per-instance placement transforms (see `apply_transforms.m`). Kept in
case the transform extraction ever needs to be redone or double-checked.

### `junk/`
Superseded exports, one-time extraction/diagnostic scripts, and abandoned
approaches from getting to the current pipeline (see history below).
Nothing load-bearing for the current workflow lives here.

## Materials (known, not yet wired into the solve)

| Part | Material |
|---|---|
| `injector` | Stainless steel  |
| `chamber` | Ceramic |
| everything else (both plates, center + outer solenoids) | Soft iron |

For a magnetostatic solve, the only material property that matters is
`RelativePermeability`. Soft iron needs a nonlinear B-H curve for
accuracy near saturation (MATLAB supports this via a function handle,
see `pde/NonlinearRelativePermeabilityExample`) — the specific soft iron
alloy is still needed to get a real B-H curve. **Gotcha**: MATLAB's
built-in material catalog (`materialProperties(Material="steel")`)
silently returns `RelativePermeability = 1` — it has no real magnetic
data — so it must not be used for the iron parts.

## Next step: multi-domain material assignment

`addCell` (used by `check_placed.m` to probe contacts) only supports
nesting one solid strictly inside another — it cannot build a geometry
where two solids share a real conformal boundary, which is what a
correctly-mated assembly needs. The original approach, prototyped
end-to-end in `new_export/scratch_classify.m` (see above):

1. `union` the iron + chamber + injector parts into one solid "structure
   blob" (union tolerates touching/overlapping solids; validated
   incrementally in `scratch_isolate_mesh.m`/`scratch_keepbound.m`).
2. Build the 5 winding-sleeve solids separately (`scratch_windings.m`,
   `windings.mat`) — these float in the air gap and stay their own cells,
   not unioned into the blob.
3. `addCell` the structure blob and all 5 windings into the air domain
   sphere (7 cells total) and mesh once, conformally.
4. For each element of the structure-blob cell, classify which original
   part (iron / chamber / injector) it falls inside via `findCell`
   (vectorized point-in-solid test), with a nearest-solid distance
   fallback for elements `findCell` can't place directly.
5. Rebuild via `fegeometry(mesh, ElementIDToRegionID)` — MATLAB's
   sanctioned mechanism for a multi-material geometry with real shared
   (conformal) boundaries (`pde/DMultidomainFegeometryObjectExample`) —
   and wire the result into a `femodel` magnetostatic solve with real
   per-region `RelativePermeability` and winding `cellLoad` currents.

### Blocker hit at step 1: `union` isn't clean across every interface

**Re-diagnosed since the paragraph above was first written — the
original "iron works, only chamber is broken" story does not hold up.**
Re-running `scratch_isolate_mesh.m` on this machine (MATLAB R2025b — the
only release installed here; `union` for `fegeometry` was introduced in
R2025a, so it's possible the original "73 faces, meshes fine" result was
produced on R2025a and the boolean kernel's tolerance behavior changed —
unconfirmed, but consistent with everything below), the iron-only chain
now fails outright at the 6th of 8 parts with `Unable to combine the
geometries`, and even the 5-part blob just before that already fails to
mesh at every `Hmax`/`Hmin` tried.

Isolating every pair of parts that actually touches (the same `addCell`
contact graph `check_placed.m` computes; automated in
`scratch_pairwise_diagnose.m`) shows the problem isn't "iron blob vs.
chamber" — it's specific individual mating interfaces, and it's worse
than one blocker:

| interface | result |
|---|---|
| `outer_solenoid_1` ↔ `top_plate` | clean (exactly additive faces), meshes |
| `outer_solenoid_1` ↔ `bottom_plate` | clean, meshes |
| `outer_solenoid_9` ↔ `top_plate` | clean, meshes |
| `outer_solenoid_9` ↔ `bottom_plate` | clean, meshes |
| `outer_solenoid_7` ↔ `top_plate` | mildly inflated (+3–10 spurious faces depending on union order), unmeshable |
| `outer_solenoid_2` ↔ `top_plate` | badly inflated (13–17 spurious faces), unmeshable at any resolution |
| `center_solenoid` ↔ `chamber` | union "succeeds" (23→49 faces) but unmeshable at any resolution |
| `injector` ↔ `chamber` | **hard failure**: `Unable to create a valid geometry. The triangulation contains degenerate triangles.` |
| `chamber` ↔ `top_plate` | same hard failure as injector↔chamber |

Of the 9 real touching interfaces in the whole assembly, 4 are clean and
5 are broken — including all 3 of chamber's contacts (only 1 of which,
iron, was previously suspected) and 2 of the 4 outer-pole-to-top-plate
mates. Two more findings narrow this further:

- **The broken pole mates correlate with placement, not part shape.**
  All 4 `outer_solenoid` copies are the same STEP file placed by
  `apply_transforms.m`'s hardcoded per-occurrence transform table.
  `outer_solenoid_1`/`_9` (clean) share `top_plate`'s exact translation
  coordinate on one axis, consistent with having been mated directly to
  `top_plate` in Onshape. `outer_solenoid_2`/`_7` (broken) instead share
  that coordinate with `chamber`/`center_solenoid`, consistent with their
  placement being derived through a *different*, longer mate chain that
  only reaches `top_plate` indirectly — any tolerance accumulated along
  that chain would surface exactly as this kind of near-but-not-quite
  coincident mating face. This is a placement/mate-chain problem, not
  something inherent to the outer-pole shape.
- **`injector`'s own STEP tessellation is unusually dirty independent of
  any union.** `scratch_check_tessellation.m` checks each part's own
  boundary triangulation for degenerate (near-zero-area) triangles:
  `injector` has 53 triangles under 1e-8 area on a 39-face part, far more
  than any other part (the 4 outer-solenoid copies and center_solenoid
  all have a small, *identical* handful — 20 or fewer, plausibly benign
  cylinder-cap artifacts common to revolved STEP tessellation — and
  `chamber`/`bottom_plate`/`top_plate` have zero). `chamber` and
  `top_plate` are each individually clean, so their mutual union failure
  is purely a placement/tolerance issue introduced by the boolean itself
  — but `injector`'s failure against `chamber` may be compounded by
  `injector`'s own dirty export, not placement alone.
- **`union(A,B)` is not symmetric.** The exact face-count inflation for a
  broken pair varies depending on which operand is unioned into which
  (e.g. `outer_solenoid_2`+`top_plate` produced 35–39 faces across
  otherwise-identical reruns depending on argument order) — the pair
  stays broken either way, but the specific symptom isn't deterministic
  across orderings. Worth keeping in mind for any future fix attempt or
  checker script: test both orderings, don't trust one.

This matters because the whole mesh-once-then-`findCell`-classify plan
above depended on every one of these unions being clean. Most aren't.

**Proposed fix for the inert parts (chamber, injector) — decision pending
as of this writing:** since chamber and injector are magnetically inert
(relative permeability ≈ 1, same as air) and their touching interfaces
only matter geometrically — not electromagnetically — for this solve,
give them a small clearance gap from whatever they touch (and from each
other) via an inflate-and-subtract, rather than a zero-gap union. This
also simplifies the pipeline: every such region becomes its own natively
separate `addCell`'d cell (like the windings already are), making the
mesh-once-then-`findCell`-reclassify step (steps 3-5 above) unnecessary
for those regions entirely.

**This fix does not cover the `outer_solenoid_2`/`_7` ↔ `top_plate`
mates.** Those are iron-to-iron interfaces that need a true zero-gap
union for flux continuity (per the reasoning above), so they can't be
gapped away the same way. Since the likely cause is a placement/mate-
chain issue in the source assembly, the real fix is on the Onshape side:
correct the pattern/mates so occurrences 2 and 7 sit exactly flush
against `top_plate` the way 1 and 9 already do, then re-extract
transforms. Not yet done — needs a decision on whether to fix this in
Onshape now or work around it in MATLAB first (e.g. re-tessellating the
mating faces before union, unconfirmed whether that would even work).

## CAD software choice: Onshape vs. Fusion 360 vs. SolidWorks

Came up while scoping the Onshape-side fix above (a parametric gap and/or
corrected mates, re-exported programmatically): does the CAD package
matter for where this pipeline is headed? Yes, mainly on how automatable
headless parameter-change-and-export is — not just "does it have an API"
generically.

- **Onshape** (current choice) — best fit, and already in use. A real
  cloud REST API: API-key auth, read/write FeatureScript parameters,
  trigger STEP export, all callable from any language/OS (including this
  Mac) with no local install or license seat consumed just to automate.
  Exactly the shape this pipeline already assumes.
- **Fusion 360** — has a genuine headless path via Autodesk Platform
  Services (Design Automation + Data Management APIs), architecturally
  similar to Onshape's, but noticeably more complex to stand up (OAuth
  app registration, "AppBundles"/"Activities") and less mature/documented
  for this use case. Its simpler API is in-app Python scripting, which
  needs a running Fusion session — at least that works natively on Mac,
  since Fusion (unlike SolidWorks) isn't Windows-only.
- **SolidWorks** — weakest fit for this need specifically. Automation is
  COM-based and desktop-bound: requires a licensed SolidWorks instance
  actually running, on Windows only. No lightweight remote-callable REST
  layer like Onshape's; batch export exists (Task Scheduler, Excel-linked
  design tables) but "change a parameter and pull a fresh STEP from a
  script on this Mac" isn't how it's built to work.

If "best for the future of the simulation architecture" means what this
pipeline already does today — source-parametric gaps, scripted
re-export, eventually sweeping a dimension programmatically — Onshape is
the clear architectural fit and SolidWorks the biggest step backward.
The real tradeoff is team familiarity/existing licenses, which is a
legitimate cost but a separate axis from API capability.

## Gotchas encountered (for future re-exports)

- Onshape's raw "Export as STEP" wraps every part in an assembly
  structure that MATLAB's STEP reader rejects
  (`STEPGeometryMustBeSolid`). Exporting each part individually as its
  own flat STEP file (as in `new_export/`) avoids this entirely.
- A STEP file can only contain **one** solid shape for `fegeometry` /
  `importGeometry` — a multi-body assembly STEP cannot be imported
  directly, flattened or not.
- Per-part STEP export does **not** preserve patterned-instance assembly
  placement — all 4 `outer_solenoid` copies exported to the identical
  local position. The fix was to separately export the whole assembly to
  STEP once, extract each occurrence's real placement transform from the
  `NEXT_ASSEMBLY_USAGE_OCCURRENCE` / `ITEM_DEFINED_TRANSFORMATION` chain,
  and apply it in MATLAB (`apply_transforms.m`) to the reliable per-part
  geometry.
- `pdegplot` silently resets `hold` to `off` after every call — re-assert
  `hold on` before each subsequent plot/legend call in a multi-part
  figure or later parts silently wipe out earlier ones.
- `union` for `fegeometry` (new in R2025a) can silently produce
  degenerate sliver faces instead of a clean shared boundary when two
  solids' mating surfaces are near-but-not-exactly coincident — it
  doesn't error, but the result then fails to mesh at any `Hmax`/`Hmin`.
  Symptom to watch for: a disproportionate face-count jump after adding
  one part to a union (see "Blocker hit at step 1" below).

## Future features / things to consider

- Full thruster material included (in progress, see above)
- **A standalone CAD-checker script**, likely necessary at some point:
  automate what `scratch_pairwise_diagnose.m` and
  `scratch_check_tessellation.m` currently do by hand into one script
  that runs after every re-export/re-transform and reports, per touching
  interface, whether the union is clean and meshable, plus per-part
  tessellation quality — rather than re-discovering broken mates one at a
  time. Not urgent today, but as the assembly gets re-exported from
  Onshape (mate fixes, added parts, etc.) this turns a manual multi-probe
  diagnosis into a single pass/fail gate.
- Force acting on solenoids
- E field sim
- Trace electron trajectory, quantify stability
- Coil thermals?

Requires MATLAB R2023b+ with the Partial Differential Equation Toolbox.

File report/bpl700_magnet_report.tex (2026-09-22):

\documentclass[10pt]{article}
\usepackage[letterpaper,margin=0.9in]{geometry}
\usepackage{lmodern}
\usepackage[T1]{fontenc}
\usepackage{amsmath}
\usepackage{graphicx}
\usepackage{booktabs}
\usepackage{array}
\usepackage{longtable}
\usepackage{siunitx}
\usepackage{xcolor}
\usepackage{caption}
\usepackage{enumitem}
\usepackage{float}
\usepackage[colorlinks=true,linkcolor=black!70!blue,urlcolor=black!70!blue,citecolor=black!70!blue]{hyperref}
\captionsetup{font=small,labelfont=bf}
\setlist{nosep,leftmargin=1.4em}
\sisetup{detect-all}
\input{generated/numbers.tex}
% \input inside a tabular leaves the following \bottomrule "misplaced";
% the primitive file read does not.
\makeatletter\newcommand\tabinput[1]{\@@input #1 }\makeatother

\title{\textbf{BPL-700 Magnet Circuit}\\[2pt]\large Spacer height sweep, coil geometry, and power-supply requirements}
\author{Marlow Nedelchev}
\date{\today}

\begin{document}
\maketitle

\begin{figure}[H]
\centering
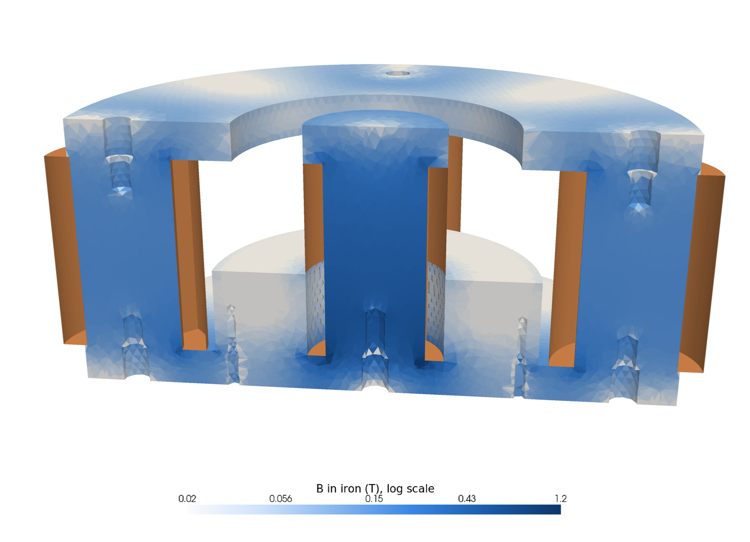
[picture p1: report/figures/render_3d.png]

\caption{BPL-700 magnet circuit, half-section through the thrust axis and one outer core, baseline geometry (spacer 0.875~in), at the 300~G operating point. Iron is coloured by $|B|$; copper is the five windings. The exit (top plate) is at the top. Nonlinear solve, A36-proxy iron.}
\label{fig:render}
\end{figure}

\section*{Summary}

This report sizes the \texttt{chamber\_spacer}, the A36 ring between the chamber's anode end and the bottom plate. Its height is set by \texttt{emag\_height} (spacer $=\texttt{emag\_height}-1.125$~in), which is also the height of every coil and core, so a shorter spacer means shorter windings. The inner winding cannot grow outward (the chamber bore sits on it), only inward by thinning the core. \NRuns{} full-3D magnetostatic solves cover spacer heights 0--0.875~in in 0.125~in steps at three inner-core diameters (1.000, 0.875, 0.750~in), each scaled to exactly 300~G radial field at the channel exit. It reports the resulting coil geometries, windings and supply requirements; choosing among them is left to the reader.

\begin{itemize}
\item \textbf{The spacer height hardly changes the field per ampere-turn.} Across the whole sweep the inner coil needs 326--339 A-turns (outer coils 207--215 each) for 300~G, a 4\% spread, of which about $\pm1$\% is mesh noise. The circuit is gap-dominated, and the exit gap does not move with the spacer.
\item \textbf{It changes the winding a great deal.} Shorter coils hold fewer turns, so the same A-turns need more current. At the current 1.000~in core, AWG~20 goes from \BaseI~A / \BaseP~W / \BaseT$^\circ$C at the full 0.875~in spacer to \ZeroI~A / \ZeroP~W / \ZeroT$^\circ$C with no spacer.
\item \textbf{Thinning the core buys that room back almost for free.} A 0.750~in core costs about 2\% more A-turns but nearly doubles the inner winding window. \emph{No spacer with a 0.750~in core needs 1.28~A and 5.4~W, essentially today's 1.27~A and 5.1~W.}
\item \textbf{Nothing approaches saturation.} The highest core flux density anywhere in the sweep is \WorstCoreB~T (\WorstCoreDesc), against a knee of 1.3--1.5~T on the measured 1020 curve. Core flux \emph{rises} with spacer height: the steel spacer wraps the inner coil and pulls leakage flux through the core.
\item \textbf{Shorter spacers shape the field slightly better.} The field at the anode end drops from 43~G to 22~G (1.000~in core) as the spacer goes from 0.875~in to 0, closer to the target lens profile, at a cost of about one point of radial purity (97.0\% to 95.9\%).
\item \textbf{Supply.} One constant-current channel for the whole series string. With AWG~20 every swept design runs at 0.72--2.25~A and under 4.5~V hot (under 10~W), so a supply rated $\geq$2.8~A and $\geq$9~V covers them all; other gauges trade current for voltage at the same power (Sec.~\ref{sec:psu}).
\end{itemize}

\section{Configuration and constraints}
\label{sec:config}

The circuit is one inner pole and four outer poles between two 0.375~in iron plates (Fig.~\ref{fig:geometry}). The top plate is the exit pole piece; the inner core carries a 1.375~in pole cap flush with it, and the radial gap between that cap and the top-plate bore is what puts the field across the discharge channel. Flux returns through the four outer cores and the bottom plate. Inner and outer windings are driven with opposite polarity from one series current.

\begin{figure}[H]
\centering

\caption{Half-section in the plane of one outer core, at the two ends of the sweep. Grey: iron (A36 plates and spacer; A108 cores). Hatched: \texttt{chamber\_spacer}. Orange: windings. Light: chamber (PTFE). Dashed blue: the plasma channel used for every field statistic in this report (r 22.10--31.75~mm, anode at $y=+3.18$~mm, exit at $y=-31.75$~mm).}
\label{fig:geometry}
\end{figure}

Measured directly from the Onshape STEP exports, not assumed:
\begin{itemize}
\item \textbf{The spacer is fixed by \texttt{emag\_height}.} The chamber and top plate never move; the chamber's anode end sits at $y=+5.59$~mm and \texttt{emag\_height} moves only the bottom plate. So
\[ h_\text{spacer} = \texttt{emag\_height} - 1.125~\text{in}, \]
and $h_\text{spacer}\ge 0$ means $\texttt{emag\_height}\ge1.125$~in. At exactly 1.125~in Onshape drops the spacer body and the bottom plate sits on the chamber. All coils and cores are \texttt{emag\_height} tall.
\item \textbf{The inner coil cannot grow outward.} The chamber bore and the spacer bore are both $r=17.46$~mm, exactly the inner coil's outer radius (OD 1.375~in). With the chamber fixed, the inner winding window is $4.76~\text{mm}\times\texttt{emag\_height}$ at the current 1.000~in core. It can only be recovered by thinning the core under the winding (\texttt{inner\_coil\_id}); the pole cap stays at 1.375~in regardless.
\item \textbf{The outer coils have room.} Outer core axes sit 62.86~mm off-axis and the chamber's outer wall is at $r=41.28$~mm, so an outer coil can reach $\approx1.70$~in OD before touching it (currently 1.5~in).
\item \textbf{Stock thicknesses.} The spacer is a single laser-cut A36 part only at a stocked thickness: 0.187, 0.250, 0.313, 0.375 or 0.500~in. Those are marked $^\dagger$ in the tables.
\end{itemize}

\section{Materials}

\begin{table}[htbp]
\centering\small
\begin{tabular}{@{}>{\raggedright}p{3.3cm}>{\raggedright}p{4.3cm}>{\raggedright}p{2.0cm}>{\raggedright\arraybackslash}p{5.2cm}@{}}
\toprule
Part & Material & Source & Magnetic model \\
\midrule
Top, bottom plates; spacer & ASTM A36, hot-rolled P\&O & SendCutSend & AISI 1008 curve as proxy (secondhand) \\
Inner, outer emag cores & ASTM A108 cold-finished bar (taken as 1018) & McMaster & measured 1020 curve, Fermilab TM-1197 \\
Windings & fiberglass-served Cu magnet wire & -- & $\mu_r=1$; current density only \\
Chamber & PTFE & -- & $\mu_r=1$ (not meshed) \\
\bottomrule
\end{tabular}
\caption{Materials. Full properties, sources and confidence ratings are in \texttt{MATERIALS.md}.}
\label{tab:materials}
\end{table}

The circuit is gap-dominated, so the channel field barely depends on the iron grade (Sec.~\ref{sec:method}). Grade does set where a thinned core saturates, which is why the cores are judged against a measured curve (Fig.~\ref{fig:core}, right). Cold drawing lowers permeability slightly relative to the measured stock; a stress-relief anneal after machining recovers it if a core ever runs near the knee.

\section{Method}
\label{sec:method}

\paragraph{Geometry.} Each point is a full-assembly STEP export from the parametrised Onshape document (5 configuration parameters), imported, meshed and solved in 3D by the Gmsh/GetDP pipeline (magnetic vector potential, edge elements, ${\sim}5.9\times10^5$ unknowns). The chamber is fixed, so the channel region is taken from its CAD-confirmed dimensions rather than re-detected per run.

\paragraph{Linear iron, and why that is enough.} Every sweep point uses linear iron ($\mu_r=1500$), about 2.5~min per solve against ${\sim}70$~min nonlinear. Checked, not assumed: on the baseline geometry the linear solve reads \LinVsNLPct\% on the exit field relative to the committed nonlinear (A36-proxy) solve at equal current. A second check re-solved the highest-core-flux geometry (0.750~in core, 0.875~in spacer) with nonlinear iron. Its half-current stage converged (9 Picard iterations), but the full-current stage stalled at a relative residual of 0.11 instead of reaching $10^{-4}$, so \emph{it is not a validated solution}. Taken for what it is, its field agrees with the linear solve to 0.3\% on the exit field and 0.5\% in the outer cores, and puts the inner-core shaft flux density 3.4\% \emph{lower} (the linear figures are conservative there). The one sizeable disagreement is the 99.9th-percentile iron field (13\% higher), i.e. a small number of high-field corner elements, which is plausibly where the Picard iteration is stuck. A finer ramp (nine stages, 50--100\%) was then tried: the 50\%, 60\% and 70\% stages converged (9, 16 and 35 iterations), but Picard contraction fell with every stage (about $2.3\times$, $1.7\times$, $1.2\times$ per iteration) and at 75\% dropped to about $1.1\times$, projecting past the 60-iteration cap, while solver memory grew to 13~GB. It was terminated. The difficulty rises with current level rather than step size, so a converged full-current check needs a Newton iteration, not a finer ramp.
Because the model is linear, each geometry needs one solve: the field scales with ampere-turns, so the A-turns for exactly 300~G at the exit follow by scaling, and so do the iron flux densities.

\paragraph{Excitation.} Inner and outer A-turns are held at the committed ratio (338 : 215 per coil, the field-direction optimum from the earlier current-ratio sweep) and scaled together to put the channel-averaged $B_r$ at the exit station at 300~G. Sweeping the ratio per geometry is a cheap follow-up (two basis solves each) if the shape results below suggest it.

\paragraph{Metrics.} The channel is split into 20 axial stations from anode to exit; $B_r$ and $B_\text{axial}$ are volume-element averages over each station. Radial purity is the mean of $B_r/|B|$. Core flux density is the mean axial $B$ across the shaft cross-section (inside 90\% of the core radius), taken at its maximum along the shaft, since leakage flux joins the core along its length.

\paragraph{Windings.} \texttt{sizing/winding\_design.py} turns A-turns into a winding. Hexagonally nested round wire; insulated diameters are single-glass-served estimates. The inner coil is wound full; the outer coils are wound to whatever turn count gives the required A-turn ratio at the same series current (or full, if the outer window runs out first). Resistance uses the radius the copper actually occupies. It reproduces the committed 260/165-turn AWG~20 design exactly.

\paragraph{Thermal.} \texttt{thermal/radiation\_balance.py}: vacuum, radiation from the outer envelope only (taken from each geometry's own mesh), emissivity 0.30, coils bonded to their cores. Temperatures feed back into copper resistance.

\section{Results}
\label{sec:results}

\subsection{Field in the circuit}
Fig.~\ref{fig:fieldmaps} shows the flux path at both ends of the sweep: up the inner core, radially across the channel from the pole cap to the top-plate bore, down the outer cores and back through the bottom plate. The field in the channel is set by that exit gap, which is identical in every configuration, so the two maps differ mainly behind the channel. With a long spacer, the steel spacer sits just 4.8~mm from the inner core, across the inner winding, and offers flux a path back to the bottom plate that bypasses the channel (this is what loads the core; Sec.~\ref{sec:results}.4). With no spacer, the bottom plate sits 2.4~mm behind the anode face instead.

\begin{figure}[H]
\centering

\caption{$|B|$ (log scale) and field lines in the plane through the axis and two opposite outer cores, at each geometry's own 300~G excitation, 1.000~in core. Left: longest spacer swept (0.875~in). Right: no spacer. Outlines: iron, windings, chamber; dashed orange: plasma channel.}
\label{fig:fieldmaps}
\end{figure}

\begin{figure}[H]
\centering

\caption{Close-up of the channel (dashed), linear colour scale in gauss, same two geometries. The field crosses the channel radially from the inner pole cap to the top-plate bore and weakens toward the anode.}
\label{fig:zoom}
\end{figure}

\subsection{Channel field shape}
Every configuration keeps the same basic lens shape: $B_r$ rises from the anode to a peak of about 317~G roughly 4~mm inside the exit plane, and is 300~G at the exit by construction (Fig.~\ref{fig:profiles}). The spacer only moves the anode half of the profile. Shorter spacers pull the anode-end field down (43~G at 0.875~in to 22~G at 0, 1.000~in core), which moves it toward the target lens and away from the anode, and they reduce the axial component there. The trade is a slightly less radial field overall: radial purity falls from 97.0\% to 95.9\% (Table~\ref{tab:magnetics}). A thinner core shifts the anode field by only a few gauss. All configurations still overshoot the idealised target in the middle of the channel; that is a property of this pole geometry, not of the spacer.

\begin{figure}[H]
\centering

\caption{Channel-averaged radial (left) and axial (right) field from anode to exit, every spacer height, 1.000~in core, each at its own 300~G excitation. Dashed grey: the target magnetic-lens profile used by \texttt{field\_quality.py}.}
\label{fig:profiles}
\end{figure}

\subsection{Ampere-turns needed}
The A-turns needed for 300~G barely move (Fig.~\ref{fig:at}). Removing the spacer entirely changes the requirement by \AtChangePct\% at the 1.000~in core, comparable to the $\pm1$\% scatter between neighbouring points, which is mesh noise (each geometry is re-meshed from scratch). The one systematic trend is the core: a 0.750~in core needs about 2\% more A-turns than a 1.000~in one, as more of the inner coil's flux leaks past the thinner core. Growing the outer coils to 1.625~in OD (one check point, 1.5~in \texttt{emag\_height}) changes the requirement by \OuterODChangePct\%, i.e. not at all: outer-coil OD is purely a winding-room choice.

\begin{figure}[H]
\centering

\caption{A-turns for 300~G at the channel exit, inner coil and each outer coil, and the resulting field per inner ampere-turn.}
\label{fig:at}
\end{figure}

\subsection{Core flux density}
Every core stays far below the knee (Fig.~\ref{fig:core}). The inner core's shaft flux density runs 0.34--0.46~T at 1.000~in, 0.45--0.56~T at 0.875~in and 0.61--0.74~T at 0.750~in, scaling roughly with $1/d^2$ as it must for a fixed flux. The outer cores sit at 0.17--0.19~T throughout. Counter-intuitively, core flux is highest at the \emph{longest} spacer. The steel spacer wraps the inner coil and gives flux a return path through the bottom plate, so the lower part of the core carries that leakage on top of the useful channel flux. Shortening the spacer removes it. The worst case in the sweep, \WorstCoreB~T, is about half the 1.3--1.5~T knee; on the measured 1020 curve the cores stay on the steep, near-linear part of the curve everywhere swept.

\begin{figure}[H]
\centering

\caption{Left: highest shaft-averaged flux density along each core at 300~G, per inner-core diameter (solid: inner core; dotted: outer cores). Right: the measured 1020 curve used for the cores and the 1008 proxy used for the plates, with the worst swept core marked. Shaded: the knee.}
\label{fig:core}
\end{figure}

\subsection{Coil geometries and windings}
Table~\ref{tab:geometry} lists every coil geometry. Tables~\ref{tab:magnetics} and \ref{tab:awg20} give the magnetics and the AWG~20 winding for each; Appendix~A has every gauge.

Three things stand out in Fig.~\ref{fig:winding}:
\begin{itemize}
\item \textbf{Current and power track winding room, not the field.} The A-turns are almost constant, so current is inversely proportional to how many turns fit. The inner window is (core-to-chamber build) $\times$ \texttt{emag\_height}, and both a short spacer and a thick core shrink it.
\item \textbf{String voltage is nearly constant} at 4.0--4.5~V hot across every AWG~20 design. For a fixed gauge $V = IR = (NI)\,\rho\,L_\text{turn}/A_\text{wire}$: it depends only on the A-turns and the mean turn length, not on how many turns fit. Since the A-turns hardly change, neither does the voltage, and power ($VI$) follows current.
\item \textbf{A thinner core offsets a shorter spacer.} Each step from 1.000 to 0.875 to 0.750~in roughly offsets 0.4~in of spacer. No spacer with a 0.750~in core (261/166 turns, 1.28~A, 5.4~W, 69$^\circ$C) matches today's design (260/165 turns, 1.27~A, 5.1~W, 61$^\circ$C) almost exactly.
\end{itemize}
Every configuration is thermally comfortable: the hottest coil is 95$^\circ$C (1.000~in core, no spacer), against a 200$^\circ$C wire-insulation limit.

\begin{table}[htbp]
\centering\small
\begin{tabular}{@{}rrrrrrrrr@{}}
\toprule
spacer & emag\_height & \multicolumn{4}{c}{inner coil} & \multicolumn{3}{c}{outer coil (each)} \\
\cmidrule(lr){3-6}\cmidrule(lr){7-9}
(in) & (in) & ID (in) & OD (in) & build (mm) & window (mm$^2$) & ID (in) & OD (in) & window (mm$^2$) \\
\midrule
\tabinput{generated/tab_geometry.tex}
\bottomrule
\end{tabular}
\caption{Coil geometry of every swept configuration. Inner coil ID = core diameter; OD is fixed at 1.375~in by the chamber bore. $^\dagger$~spacer at a stocked A36 thickness.}
\label{tab:geometry}
\end{table}

\begin{table}[htbp]
\centering\small
\begin{tabular}{@{}rrrrrrrrrr@{}}
\toprule
spacer & core & \multicolumn{2}{c}{A-turns for 300 G} & $B_r$ peak & $B_r$ anode & radial & \multicolumn{2}{c}{shaft $|B|$ (T)} & iron \\
\cmidrule(lr){3-4}\cmidrule(lr){8-9}
(in) & (in) & inner & outer ea. & (G) & (G) & purity (\%) & inner & outer & p99.9 (T) \\
\midrule
\tabinput{generated/tab_magnetics.tex}
\bottomrule
\end{tabular}
\caption{Magnetics per configuration, at each one's 300~G excitation (linear iron).}
\label{tab:magnetics}
\end{table}

\begin{table}[htbp]
\centering\small
\begin{tabular}{@{}rrrrrrrrrrrr@{}}
\toprule
spacer & core & \multicolumn{2}{c}{inner} & \multicolumn{2}{c}{outer (each)} & $I$ & $R_{20}$ & $V_\text{hot}$ & $P_\text{hot}$ & $T_\text{coil}$ & wire \\
\cmidrule(lr){3-4}\cmidrule(lr){5-6}
(in) & (in) & turns & layers & turns & layers & (A) & ($\Omega$) & (V) & (W) & ($^\circ$C) & (m) \\
\midrule
\tabinput{generated/tab_awg20.tex}
\bottomrule
\end{tabular}
\caption{AWG~20 winding for every configuration (the committed gauge), series string of all five coils. Other gauges: Appendix~A.}
\label{tab:awg20}
\end{table}

\begin{figure}[H]
\centering

\caption{AWG~20: series current, string voltage and power at operating temperature, and hottest-coil temperature, per spacer height and core diameter.}
\label{fig:winding}
\end{figure}

\section{Power-supply requirements}
\label{sec:psu}

Nothing in the magnetics depends on the gauge: only the ampere-turn product reaches the field. The gauge sets how that product splits into current and voltage, and therefore which supply fits. Table~\ref{tab:psu} gives, for each gauge, the envelope over \emph{every} swept geometry, so a supply chosen from it covers whichever spacer height is picked. Fig.~\ref{fig:psu} shows the same designs as operating points.

\begin{table}[htbp]
\centering\small
\begin{tabular}{@{}rccccl@{}}
\toprule
AWG & current (A) & max voltage, hot (V) & max power (W) & string $L$ (mH) & suggested supply rating \\
\midrule
\tabinput{generated/tab_psu.tex}
\bottomrule
\end{tabular}
\caption{Supply envelope per wire gauge across all swept geometries (one series string, all five coils). ``Hot'' is at the steady-state coil temperature. Suggested rating: 1.25$\times$ the highest current (room for the linear-model and wire-diameter uncertainty and a field margin above 300~G) and 2$\times$ the highest hot voltage (room for lead resistance and ramping into the inductance).}
\label{tab:psu}
\end{table}

\begin{figure}[H]
\centering

\caption{Every swept geometry in every gauge as a (current, voltage) operating point, with lines of constant power. Gauge moves a design along a constant-power line; geometry moves it across the lines.}
\label{fig:psu}
\end{figure}

What the supply needs, independent of gauge:
\begin{itemize}
\item \textbf{Constant-current (CC) regulation.} The field follows current, not voltage; copper resistance rises about 0.4\%/K as the coils warm, so a constant-voltage supply would let the field drift down by the same amount. Any bench supply with a CC mode works; the load is a plain resistor-inductor.
\item \textbf{One channel is enough.} All five coils run in series from one current. The inner/outer ratio is set by turn counts, not by separate supplies. A second supply (or a trim resistor on one leg) is only needed to tune the ratio in the lab.
\item \textbf{Inductance, and switching off.} Stored field energy at the operating point is \StoredEnergyMJ~mJ (from the nonlinear baseline solve), independent of gauge, so the string inductance is $L = 2W/I^2$ (Table~\ref{tab:psu}). Ramp the current up and down rather than stepping it, and put a flyback diode (or TVS) across the string so an open circuit or relay under current cannot generate a large voltage spike. The time constant $L/R$ is tens of milliseconds, so ripple is heavily filtered and does not matter.
\item \textbf{Polarity.} The inner winding is driven opposite to the outer windings (flux crosses the channel from the inner pole to the top plate). Wire the string so the inner coil's sense is reversed relative to the four outer coils, and check it with a gaussmeter at first power-up: wrong polarity collapses the channel field.
\item \textbf{Floating output.} The coils sit next to the discharge; an isolated (floating) output keeps the magnet circuit independent of the discharge supply's reference.
\end{itemize}

\section{Limitations and open items}
\begin{itemize}
\item \textbf{Insulated wire diameters are estimates.} They set turn counts, which can move by 10--20\% with a real datasheet. That moves current and voltage (and the supply choice), not the field and barely the power.
\item \textbf{Linear iron.} Each point is a linear solve. It is checked against a converged nonlinear solve only at the baseline geometry; the worst-case nonlinear check did not converge (Sec.~\ref{sec:method}), though its unconverged field agrees with the linear one in the channel and cores. The plates' B-H curve is a proxy (1008 for A36). The circuit is gap-dominated, so this mostly matters for the core saturation margin, which is judged against the measured 1020 curve.
\item \textbf{Fixed inner/outer A-turn ratio.} Re-optimising the ratio per geometry could recover some field shape at short spacers.
\item \textbf{The 300~G target is not derived} from the plasma requirements (the top-level sizing script assumes 150~G). The results scale linearly: halving the target halves every A-turn and current figure and quarters every power.
\item \textbf{Magnets-only thermal.} No plasma heat load; emissivity 0.30 assumed (\texttt{thermal/README.md} has the sensitivity).
\end{itemize}

\appendix
\section{Every gauge, every geometry}
\small
\begin{longtable}{@{}rrrcrrrrrrr@{}}
\toprule
spacer & core & AWG & turns in/out & $I$ (A) & $R_\text{hot}$ ($\Omega$) & $V_{20}$ & $V_\text{hot}$ & $P_\text{hot}$ (W) & $T_\text{coil}$ ($^\circ$C) & $J$ (A/mm$^2$) \\
(in) & (in) & & & & & (V) & (V) & & & \\
\midrule
\endhead
\tabinput{generated/tab_all_gauges.tex}
\bottomrule
\end{longtable}
\normalsize

\section{Reproducing this report}
From the repository root:
\begin{verbatim}
cd gmsh_getdp/assembly
python emag_sweep.py --validate            # linear vs committed nonlinear, baseline
python emag_sweep.py                       # full grid, resumable (~1 h)
python emag_sweep.py --nonlinear h1.125_ci0.750_oo1.500
cd ../..
python report/render_3d.py
python report/make_report.py               # figures, tables, PDF (needs tools/tectonic)
\end{verbatim}

\end{document}

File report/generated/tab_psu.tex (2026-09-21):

16 & 1.61--5.73 & 1.7 & 10.0 & 4--51 & $\geq$7.2 A, $\geq$3 V \\
18 & 1.12--3.40 & 2.7 & 9.3 & 11--104 & $\geq$4.2 A, $\geq$5 V \\
20 & 0.72--2.25 & 4.5 & 10.0 & 26--252 & $\geq$2.8 A, $\geq$9 V \\
22 & 0.48--1.51 & 7.0 & 10.6 & 58--570 & $\geq$1.9 A, $\geq$14 V \\
24 & 0.33--0.95 & 11.4 & 10.8 & 146--1183 & $\geq$1.2 A, $\geq$23 V \\

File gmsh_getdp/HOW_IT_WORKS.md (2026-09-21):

# How this pipeline works: code and physics side by side

This walks through `toy_test/` and `assembly/` step by step, connecting
what the code does to what it means physically. For status/setup/known
issues, see `README.md` instead — this file is about *why* each step
exists.

## 1. The physics problem

We want the magnetic field `B` produced by current-carrying coils and
shaped by iron pole pieces. The governing equations (magnetostatics — no
time variation, so no induced E-field to worry about) are:

```
curl H = J        (Ampere's law: current is the source of H)
div B  = 0         (no magnetic monopoles)
B = mu * H          (material response: B and H related by permeability)
```

Two hard parts, both handled the same way in `toy_test` and `assembly`:

- **`div B = 0` has to hold everywhere, exactly**, not just approximately.
  Directly solving for `B`'s three components with a generic FEM
  discretization doesn't guarantee that. The standard fix: introduce the
  **magnetic vector potential** `A`, defined by `B = curl A`. Since
  `div(curl(anything)) = 0` identically, `div B = 0` is now automatic —
  solved by construction, not by the mesh. Substituting into Ampere's law
  gives the actual PDE we solve:

  ```
  curl( nu * curl A ) = J        where nu = 1/mu  (reluctivity)
  ```

  This is what every `.pro` file's `Formulation` block encodes (section 6
  below).

- **Real space is infinite; a mesh isn't.** The field technically extends
  to infinity, decaying with distance. Both scripts truncate this by
  building a large sphere of "air" around the real hardware (`air_radius
  = 8 * <assembly half-extent>` in both `build_toy.py` and
  `build_assembly.py`) and forcing `A = 0` on its outer boundary — see
  section 4. Physically this says "far enough away, there's no field,"
  which is true in the limit and a good approximation at 8x the source's
  own size.

## 2. Geometry construction (`build_toy.py`, `build_assembly.py`)

### Building the conductor and iron as solids

`toy_test/build_toy.py` builds one hollow cylinder (a coil) directly with
Gmsh/OpenCASCADE primitives (`occ.addCylinder`, then `occ.cut` to hollow
it out) sitting inside an air sphere. This is the "can I trust the
formulation at all" check — no real CAD, no placement complexity, just
geometry simple enough to compare against a hand-derivable analytic
answer (see section 8).

`assembly/build_assembly.py` does the same job on the real BPL-700
hardware: imports a single whole-assembly Onshape STEP export, which
carries every part's real placement and name already (no hand-maintained
transform table), and fuses the 7 real iron parts (top plate, bottom
plate, center pole, 4 outer poles) into one solid — folding them in
**one at a time**, since fusing them in a single batch call leaves 3
disjoint solids on this geometry (see `README.md`).

**Why fuse them at all, physically?** In the real hardware these iron
pieces are bolted/mated together into one continuous magnetic circuit —
flux has to pass through the top plate into an outer pole and back out
the bottom plate without any discontinuity. For the FEM mesh to represent
that correctly, the elements on either side of each mating face need to
share exactly the same nodes there (a *conformal* mesh) — otherwise the
solver sees two disconnected iron blobs with an air gap between them,
which is wrong: a real air gap of even a fraction of a millimeter in a
magnetic circuit adds enormous reluctance (see section 6) and would
visibly change the answer. This was the exact step that broke in
MATLAB (`../matlab/README.md`, "Blocker hit at step 1") — not a physics
problem, a numerical-tolerance one: two real STEP surfaces meant to be
coincident come in a few microns apart, and MATLAB's boolean kernel
couldn't decide whether that counts as touching. Gmsh/OCC's
`Geometry.ToleranceBoolean` fuzzy tolerance is the fix — it explicitly
tells the kernel how much slack to allow before treating two surfaces as
the same one.

**Why are chamber and injector left out entirely?** Both are magnetically
inert — ceramic and non-magnetic stainless steel, `mu_r ~= 1`, the same
as air. Ampere's law doesn't distinguish a `mu_r=1` object from empty
space; leaving that volume unlabeled and letting it fall into the "Air"
region has zero effect on `B`. This isn't a shortcut around the physics,
it's recognizing the physics doesn't care — see the long comment at the
top of `build_assembly.py` for the two geometry problems this also
sidesteps.

### The winding sleeves are a *homogenized* current source, not real wire

The windings come in from the STEP as real coil solids (Onshape exports
them at the configured ID/OD), and are treated as one smeared-out
conductor rather than hundreds of individual turns of real wire. This is
standard practice:
a coil of `N` turns carrying current `I`, wound tightly enough that
individual turns are much smaller than the mesh, is magnetically
equivalent to a solid conductor carrying a smeared-out **bulk current
density**

```
J = N * I / A_cross
```

flowing azimuthally around the pole axis.

**`A_cross` here is the coil's r-z section — radial thickness × height —
not the annulus `π(r_o² − r_i²)`.** This distinction is the whole game,
and getting it wrong is subtle enough that it survived in this repo for
months: since the current runs *azimuthally*, every turn crosses a plane
that *contains* the axis, so that rectangle is the surface the total
`N·I` passes through. The annulus is the cross-section for current
flowing *along* the axis, which is not what a solenoid does. On these
coils the annulus is 1.8–1.9× larger, so using it applies roughly half
the intended ampere-turns while looking entirely reasonable.

`build_assembly.py` gets this area from Pappus's theorem
(`A = V / 2πr_mean`) using the solid's own volume, rather than from
nominal dimensions, so it stays right for the small fillets real CAD
coils carry.

Meshing every real turn would be enormously more expensive for no
accuracy gain at this scale — see section 5 for how that current density
is actually built into the GetDP source term.

Note that the packing factor never appears. The homogenized conductor
fills the whole coil envelope; copper fraction affects the coil's
*resistance*, and therefore the supply voltage and dissipation, but not
the field. Only `N·I` and the envelope matter magnetically.

### Fragmenting everything together

Both scripts finish geometry construction with one big `occ.fragment()`
call across every solid (iron, windings, air sphere). **Physically, this
is what makes the field continuity conditions at material interfaces
exact.** At any interface between two different materials, Maxwell's
equations require:

- the *tangential* component of `H` to be continuous,
- the *normal* component of `B` to be continuous.

Between iron (`mu_r` in the thousands) and air (`mu_r=1`), that means `B` bends
sharply at the boundary — field lines refract, much like light at a
lens surface, entering the iron nearly along the surface normal
regardless of the field direction in air (this is *why* iron pole pieces
work at all: they funnel and concentrate flux). A finite-element mesh can
only represent that correctly if the mesh nodes exactly coincide at the
interface (a "conformal" mesh) — `fragment()` is what guarantees that,
by construction, for every pair of solids that touch.

## 3. Units bookkeeping (not physics)

`build_assembly.py` scales every imported STEP part by `0.001` right
after import. This has nothing to do with the physics — it's a data
bug workaround: the STEP files' header declares `SI_UNIT(METRE)` but the
actual coordinate values are physically millimeters (confirmed by
comparing the imported bounding box against the known real part size).
MATLAB's importer silently assumes mm and rescales; Gmsh's doesn't. Get
this wrong and every length in the model — and therefore every field
value, since field strength depends on geometry — is off by 1000x.
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

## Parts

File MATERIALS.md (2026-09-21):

# Material properties

Every material property used anywhere in this repo, what uses it, where it
came from, and how much it should be trusted. Added because several
numbers in this project were placeholders that looked like data, and one
of them (the iron B-H curve) survived months of use before anyone asked
where it came from.

## How to read the confidence column

| tag | meaning |
|---|---|
| **measured** | measured on the actual BPL-700 hardware. Nothing here qualifies yet. |
| **verified** | the cited source was fetched and the value read directly out of it |
| **corroborated** | consistent across several independent secondary sources; no primary read |
| **secondhand** | single secondary source, primary inaccessible |
| **estimate** | representative engineering value, no specific source |
| **constant** | defined or standard physical constant |
| **derived** | computed from another row in this file |

---

## ASTM A36 structural steel

Top plate, bottom plate and `chamber_spacer` (confirmed 2026-09-21: the
spacer is the same soft iron as the plates). The emag cores are a
different grade -- see "ASTM A108 cold-finished bar" below.

### Procurement source

Parts come from **SendCutSend hot-rolled mild steel**, specified as
**A36/A1018 HRP&O** (hot rolled, pickled and oiled). They also stock 1008
cold rolled, but only to 0.135 in -- too thin for anything in this
assembly, which is what selects A36.

| property | value | confidence |
|---|---|---|
| grade | A36 / A1018 HRP&O | **verified** |
| carbon content | 0 to 0.26% | **verified** |
| manganese | up to ~1.2% | corroborated |
| density | 7.9 g/cm^3 (supplier: 7.85) | **verified** |
| tensile strength (ultimate) | 480 MPa (69 ksi) | **verified** |
| yield strength | 290 MPa (41 ksi) | **verified** |
| available thicknesses | .187 / .250 / .313 / .375 / .500 in | **verified** |
| laser cutting tolerance | +/-.005 in | **verified** |
| max part size | 30 x 44 in (30 x 56 in on custom quote) | **verified** |

Sources: [SendCutSend -- mild steel][scs], [makeitfrom.com ASTM A36][mifa36].

**Manufacturability.** The 0.375 in plates are a direct hit: A36 is
stocked at exactly .375 in, so each plate is a single laser-cut piece. No
lamination, and none of the interlayer-reluctance concern that a laminated
stack would have brought.

| part | thickness / dia | A36 sheet? |
|---|---|---|
| top plate | 9.53 mm (0.375 in) | **yes, exact stock thickness** |
| bottom plate | 9.53 mm (0.375 in) | **yes, exact stock thickness** |
| chamber_spacer | emag_height - 1.125 in (0 to 22.2 mm) | **yes at 0.187 / 0.250 / 0.313 / 0.375 / 0.500 in**, i.e. emag_height 1.312 / 1.375 / 1.438 / 1.500 / 1.625 in |
| outer emag core (x4) | 25.4 mm dia shaft | no -- A108 bar, see below |
| inner emag core | 25.4 mm dia shaft (= inner_coil_id), 34.9 mm pole cap | no -- A108 bar, see below |

(An earlier version of this table gave the inner core as 42.9 mm dia; the
CAD measures a 25.4 mm shaft under the winding and a 34.9 mm pole cap.)

The spacer is an annulus (r 17.46-41.28 mm) whose height tracks
emag_height, so a spacer height that lands on a stock thickness is a single
laser-cut part, and one that doesn't needs a stack or machining. Worth
weighing in the spacer-height trade (`gmsh_getdp/assembly/emag_sweep.py`).

Laser cutting leaves a heat-affected zone with altered microstructure at
every cut edge; the Fermilab measurement cited below deliberately sampled
"far away from the flame cutting region" for this reason. On parts this
size the HAZ is a non-trivial fraction of the whole.

### Magnetic

| property | value | used by | confidence |
|---|---|---|---|
| DC magnetization curve | 19 points, H 0-397887 A/m, B 0-2.585 T | `gmsh_getdp/assembly/generate_regions.py` | **secondhand** |
| saturation (B at 1000 Oe) | 2.165 T | -- | derived |
| peak relative permeability | 2164, at H = 318 A/m | -- | derived |
| mu_r at this design's peak iron field | ~1935 at 1.023 T | -- | derived |
| Curie temperature | ~770 C | `thermal/radiation_balance.py` limit | estimate |

**The curve in the model is AISI 1008 data, used as a proxy for A36.** No
numeric A36 B-H table could be obtained; the published A36 magnetization
work is transformer-tank literature behind paywalls. It is deliberately
not relabelled.

A36 carries up to 0.26% carbon against 1008's ~0.08%, plus up to 1.2%
manganese -- more pearlite, more domain-wall pinning, so **real A36 is
less permeable than this curve and the model is optimistic about the
iron**. Partly offsetting: this A36 is hot-rolled, a more relaxed
microstructure than cold-rolled 1008. Empirically, swapping the generic
GetDP curve for 1008 dropped mu_r 2.7x and moved the channel field 3.9%;
if A36 is another ~1.8x down, expect a few percent more, i.e. a design
current nearer 1.35 A than 1.30 A. That is an extrapolation, not a
result.

The B-H points originate in the Ansys Maxwell SV material library and were
transcribed via a public engineering forum. The primary source returned
HTTP 403 and could not be re-read, so this is the weakest-provenance
number in the project that anything actually depends on.

Reasons to believe it is genuine digitized data rather than invented:
every H value is an exact Oersted multiple (2, 4, 6, 8, 10, 20, 40, 60,
80, 100, 200, 400, 600, 800, 1000, 2000, 4000, 5000 Oe), which is how
pre-SI magnetization tables were published; the curve is monotonic in both
variables; differential permeability rises then falls as a real
magnetization curve must; and B at 1000 Oe lands in the 2.1-2.2 T band
expected of low-carbon steel.

Reasons to stay cautious:

- **AISI 1008 is not an electrical steel.** ASTM imposes no magnetic
  requirement on it at all. Two suppliers' 1008 may differ materially and
  neither is obliged to match this curve.
- **Processing dominates.** Peak mu_r of 2164 suggests as-rolled rather
  than annealed material; annealed low-carbon steel reaches 3000-5000.

**Why this matters less than it looks.** The magnetic circuit is
gap-dominated: at the design point the 37.4 mm air gap costs ~893
A-turns while the 227 mm iron path costs ~9. Halving or doubling mu_r
moves the total by well under a percent. What the iron buys is not
sensitivity to its own grade but the ~22x reduction in required A-turns
versus having no iron at all (that same path would cost ~18,800 A-turns
at mu_r = 1). Grade is a detail; presence is not.

### Thermal and physical

All from [makeitfrom.com ASTM A36 (SS400, S275)][mifa36], fetched and read
directly.

| property | value | used by | confidence |
|---|---|---|---|
| thermal conductivity | 50 W/m-K | justifies the isothermal-iron assumption | **verified** |
| specific heat capacity | 470 J/kg-K | carried for a future transient model | **verified** |
| density | 7900 kg/m^3 (supplier: 7850) | as above | **verified** |
| max service temperature | 400 C | `thermal/radiation_balance.py` limit | **verified** |
| elastic modulus | 190 GPa | unused | **verified** |
| thermal expansion | 12 um/m-K | unused | **verified** |
| electrical conductivity | 12% IACS | unused (relevant only to eddy currents) | **verified** |
| melting range | 1420-1460 C | unused | **verified** |

---

## ASTM A108 cold-finished bar (emag cores)

Inner and outer emag cores. Round turned parts, so they come from bar
stock rather than SendCutSend sheet: **McMaster "multipurpose low-carbon
steel" rod, ASTM A108**. A108 is a specification for cold-finished carbon
bar and covers several grades; for this product it is taken to be
**1018, cold drawn** (see "Open questions").

### Physical and thermal

From [makeitfrom.com -- cold drawn 1018][mif1018], fetched and read
directly.

| property | value | confidence |
|---|---|---|
| carbon | 0.15-0.20% | **verified** |
| manganese | 0.6-0.9% | **verified** |
| density | 7.9 g/cm^3 | **verified** |
| tensile strength (ultimate) | 480 MPa | **verified** |
| yield strength | 400 MPa | **verified** |
| thermal conductivity | 52 W/m-K | **verified** |
| specific heat | 470 J/kg-K | **verified** |
| max service temperature | 400 C | **verified** |
| electrical conductivity | 7.0% IACS | **verified** |

Thermally it is interchangeable with A36 (same conductivity, heat
capacity and service limit), so the thermal model's single isothermal
iron node covers both without change.

### Magnetic

| property | value | confidence |
|---|---|---|
| DC magnetization curve | measured 1020, 21 points, 0-1.9 T | **verified** (primary source read; grade is a proxy) |
| mu_r at 1.0 T | ~2170 | derived |
| mu_r at 1.2 T | ~1460 | derived |
| mu_r at 1.4 T | ~820 | derived |
| mu_r at 1.5 T | ~520 | derived |

Curve: [Fermilab TM-1197][fnal] Table 2, toroids machined from purchased
1020 stock and measured by Arnold Engineering. The report PDF was fetched
and all 21 rows read off the scanned table page, not just its OCR text.
Stored as `FNAL1020_B`/`FNAL1020_H` in
`gmsh_getdp/assembly/generate_regions.py`.

**This is a much better-provenanced curve than the plates' A36 proxy** --
a primary measurement, not a forum transcription -- but it is still 1020
standing in for 1018. The two are adjacent plain-carbon grades (1018:
0.15-0.20% C, 1020: 0.18-0.23% C), so the curve should be close. Cold
drawing adds residual strain, which lowers permeability relative to
annealed bar; FNAL describes its samples as behaving like hot-rolled
material. If the cores ever run near the knee, a stress-relief anneal
after machining is the cheap fix.

What the curve is used for: the core saturation margin in the spacer
sweep. The sweep itself runs linear iron, since the channel field is
insensitive to iron grade (gap-dominated circuit); what grade does
control is where a thinned core saturates. The knee on this curve is
around 1.3-1.5 T (mu_r falls from ~1460 at 1.2 T to ~520 at 1.5 T).

The same report's Table 1 is a measured **1008** curve -- a primary-source
candidate to replace the secondhand Maxwell 1008 data the plates' proxy
uses. Not yet transcribed.

---

## Copper (windings)

| property | value | used by | confidence |
|---|---|---|---|
| resistivity at 20 C | 1.68e-8 ohm-m | `thermal/radiation_balance.py` | constant |
| temperature coefficient | 0.00393 /K | as above | constant |
| AWG bare diameters | 16: 1.291, 18: 1.024, 20: 0.812, 22: 0.644, 24: 0.511 mm | winding trade study | constant |

Standard annealed-copper values. The magnetics solve does **not** use
copper properties at all -- windings enter only as a prescribed current
density, and `nu[Windings] = 1/mu0` treats them as non-magnetic.

---

## Fiberglass-served magnet wire

Chosen for insulation quality and plasma arc resistance rather than
temperature capability.

| property | value | used by | confidence |
|---|---|---|---|
| insulated OD, single glass serving | 16: 1.45, 18: 1.18, 20: 0.96, 22: 0.79, 24: 0.65 mm | turns-that-fit calculation | **estimate** |
| insulated OD, double glass serving | 16: 1.58, 18: 1.30, 20: 1.09, 22: 0.92, 24: 0.78 mm | as above | **estimate** |
| continuous temperature limit | 200 C | `thermal/radiation_balance.py` limit | **estimate** |

**These are the softest inputs in the winding design.** The insulated
diameters set how many turns fit, which sets the current and voltage (not
the field, and not the dissipation -- see
`gmsh_getdp/README.md` "Solenoid winding design"). A real wire datasheet
could move turn counts by 10-20%.

The 200 C limit is deliberately conservative; glass serving itself
tolerates far more and the real ceiling depends on the binder. If that is
firmed up, PTFE becomes the binding thermal constraint instead.

---

## PTFE (chamber)

| property | value | used by | confidence |
|---|---|---|---|
| max continuous service temperature | 260 C | `thermal/radiation_balance.py` limit | **verified** |
| thermal conductivity | 0.24-0.25 W/m-K | not used (PTFE has no source term) | corroborated |
| relative permeability | ~1 | why it is excluded from the FEM domain | constant |
| arc resistance (ASTM D495) | 700 s | not modelled; motivates the material choice | **verified** |
| transition points | 19 C and 327 C | -- | **verified** |
| decomposition | appreciable above 400 C | -- | **verified** |

Magnetically PTFE is indistinguishable from vacuum, which is why
`build_assembly.py` leaves the chamber out of the solid model entirely --
that is a recognition that the physics does not care, not a shortcut.

Thermally it matters despite having no heat source of its own: it floats
at the iron temperature and has the lowest limit of anything in the
build, so it sets the current ceiling.

Note PTFE is a poor choice once plasma is actually present (erosion,
outgassing). Presumably a test article rather than the flight part.

---

## Surface emissivity

The single most consequential thermal input: it moves the design-point
temperature from 40 C to 121 C across plausible finishes, more than any
geometric detail the model resolves. From [design1st emissivity
tables][emis], fetched and read directly.

| surface | emissivity | confidence |
|---|---|---|
| steel, polished | 0.066 | **verified** |
| iron, polished | 0.14-0.38 | **verified** |
| **mild steel** | **0.20-0.32** | **verified** |
| iron plate, rusted red | 0.61 | **verified** |
| sheet, rough oxide layer | 0.81 | **verified** |
| black anodize | 0.88 | **verified** |
| black paints (3M Black Velvet, Chemglaze Z306) | 0.91 | **verified** |

`thermal/radiation_balance.py` defaults to **0.30**, which is at the
*optimistic* end of the sourced 0.20-0.32 mild-steel band. At 0.20 the
design point runs 77 C rather than 61 C. The script sweeps emissivity for
exactly this reason -- read the sweep, not the single default.

Blackening the exterior is the cheapest thermal margin available: real
black coatings reach 0.88-0.91, better than the 0.80 used as the
"blackened" case, and would drop the design point to ~40 C.

---

## Vacuum / air

| property | value | used by | confidence |
|---|---|---|---|
| mu0 | 4*pi*1e-7 H/m | everywhere | constant |
| relative permeability of air | 1 | `nu[Air] = 1/mu0` | constant |
| Stefan-Boltzmann constant | 5.670374419e-8 W/m^2-K^4 | `thermal/radiation_balance.py` | constant |
| ambient (chamber wall) temperature | 300 K | thermal boundary condition | **estimate** |

No convection and no conduction to a mount are assumed. If the real
fixture bolts the thruster to something cold, the thermal model is
conservative.

---

## Open questions

- **Which A108 grade the core bar is.** A108 is a cold-finished-bar
  specification, not a grade; McMaster's "multipurpose low-carbon" rod is
  taken to be 1018. Worth confirming on the order/cert.
- **No numeric A36 B-H curve.** The model runs 1008 data as a proxy, which
  is optimistic about the iron. This is the single weakest input that
  anything depends on.
- **The 300 G channel-exit target is not derived.**
  `sizing/basic_het_sizing.py` assumes 150 G for its magnetization check.
  Those two numbers disagree by 2x and nothing currently reconciles them.
  Unlike most entries here, this one would move the design point, not just
  its uncertainty band.
- **Nothing in this file is measured on the actual hardware.** The B-H
  curve and the emissivity are the two worth measuring if anything is
  going to be.

---

## Sources

- [makeitfrom.com -- ASTM A36 (SS400, S275) Structural Carbon Steel][mifa36] -- iron thermal/physical properties
- [makeitfrom.com -- SAE-AISI 1008 (G10080) Carbon Steel][mif1008] -- 1008 properties, for the proxy B-H comparison
- [design1st -- Thermal Emissivity Values][emis] -- emissivity tables
- [The Plastic Shop -- PTFE Technical Information][ptfe] -- PTFE service temperature, arc resistance
- [FEMM -- DC Magnetization Curves of Soft Magnetic Materials][femm] -- context on low-carbon steel B-H data and its origin (Metals Handbook, 8th ed., Vol. 1, ASM 1966)
- [makeitfrom.com -- cold drawn 1018 carbon steel][mif1018] -- core (A108) physical/thermal properties
- [SendCutSend -- cold rolled mild steel][scs] -- **procurement source**; grade, mechanical properties, thicknesses, tolerances
- [FNAL TM-1197 via INIS -- B vs H curves for 1008 and 1020 steels][fnal] -- measured toroid curves. **Table 2 (1020) is transcribed and is the core material's curve.** Table 1 (1008) is the best candidate for replacing the plates' secondhand B-H proxy; not yet transcribed.

[mif1008]: https://www.makeitfrom.com/material-properties/SAE-AISI-1008-G10080-Carbon-Steel
[mif1018]: https://www.makeitfrom.com/material-properties/Cold-Drawn-1018-Carbon-Steel
[mifa36]: https://www.makeitfrom.com/material-properties/ASTM-A36-SS400-S275-Structural-Carbon-Steel
[emis]: https://www.design1st.com/Design-Resource-Library/engineering_data/ThermalEmissivityValues.pdf
[ptfe]: https://www.theplasticshop.co.uk/ptfe-technical-information.html
[femm]: https://www.femm.info/wiki/SoftMagneticMaterials
[fnal]: https://inis.iaea.org/records/wmz02-45d12
[scs]: https://sendcutsend.com/materials/mild-steel/cold-rolled/

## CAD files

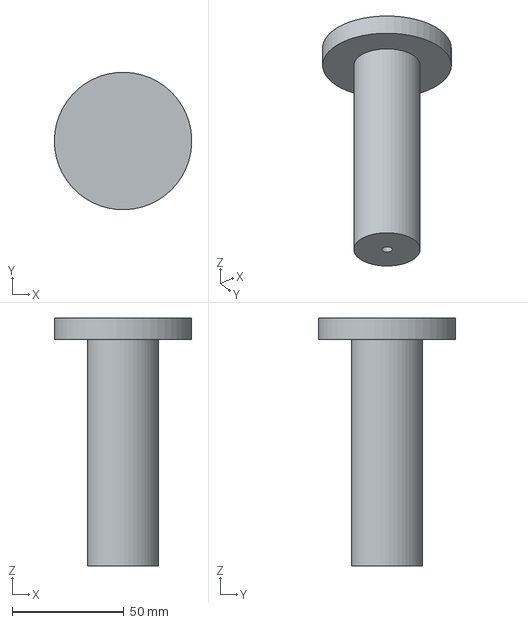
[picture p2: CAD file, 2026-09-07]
matlab/new_export/BPL-700 Assembly - center_solenoid-1__Body1.step
61.5 x 61.6 x 111.1 mm

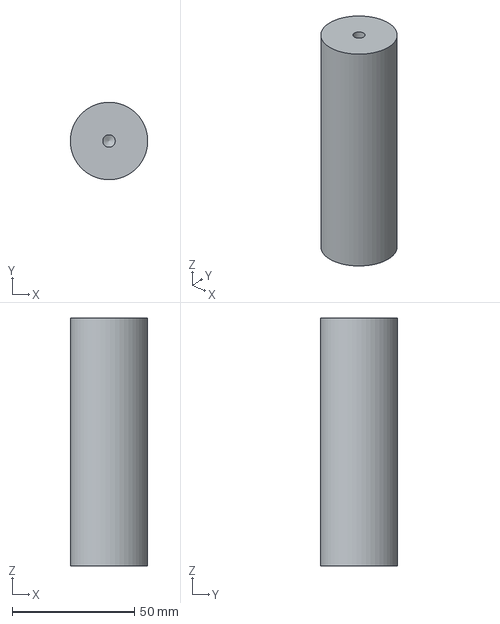
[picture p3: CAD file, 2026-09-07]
matlab/new_export/BPL-700 Assembly - outer_solenoid-1__Body1.step
31.7 x 31.7 x 101.6 mm

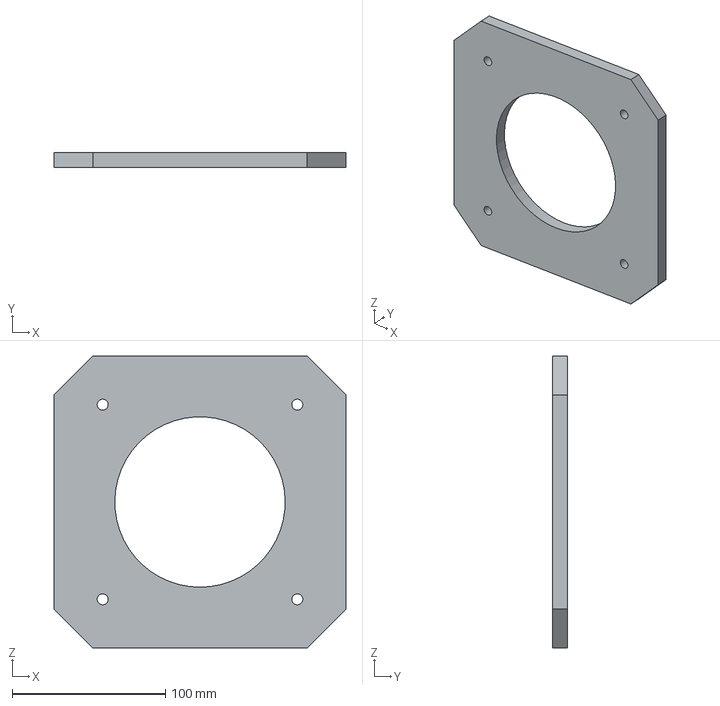
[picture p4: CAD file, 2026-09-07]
matlab/new_export/BPL-700 Assembly - top_plate-1__Body1.step
190.5 x 9.53 x 190.5 mm

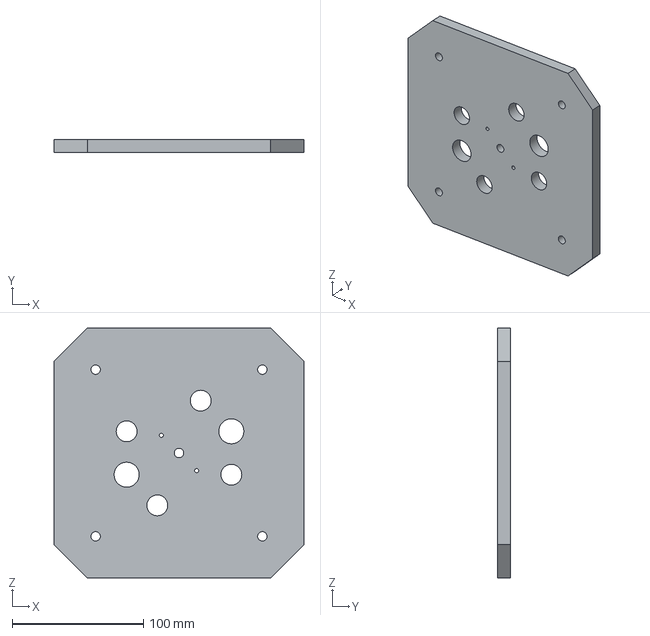
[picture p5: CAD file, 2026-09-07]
matlab/new_export/BPL-700 Assembly - bottom_plate-1__Body1.step
190.5 x 9.53 x 190.5 mm

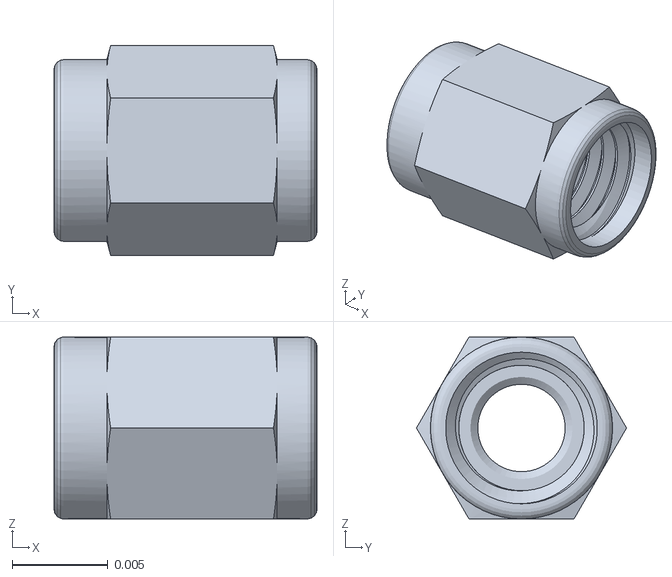
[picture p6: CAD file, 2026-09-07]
matlab/junk/stl/BPL-700 Assembly - Cut-Revolve1.stl
0.0138 x 0.011 x 0.00953

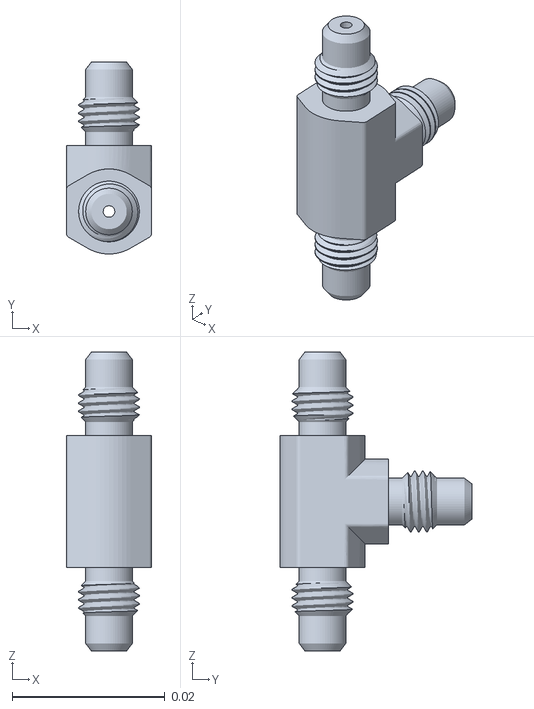
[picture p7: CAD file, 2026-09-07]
matlab/junk/stl/BPL-700 Assembly - CirPattern2.stl
0.0111 x 0.0251 x 0.0391

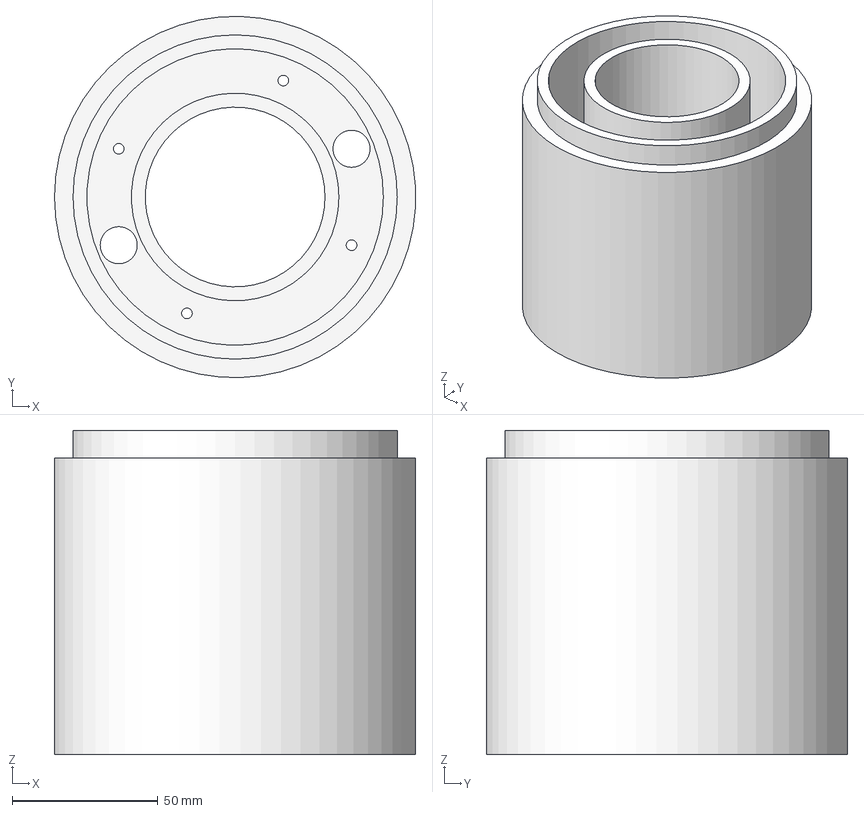
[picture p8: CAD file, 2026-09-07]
matlab/new_export/BPL-700 Assembly - chamber-1__Body1.step
123.7 x 123.8 x 111.1 mm

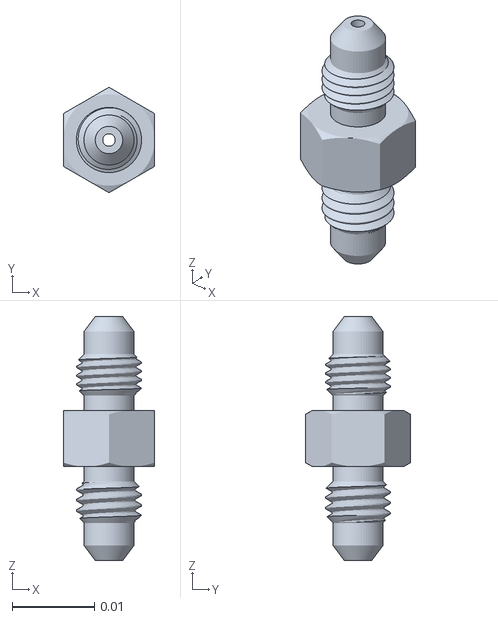
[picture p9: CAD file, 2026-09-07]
matlab/junk/stl/BPL-700 Assembly - Cut-Sweep2.stl
0.0111 x 0.0128 x 0.0297

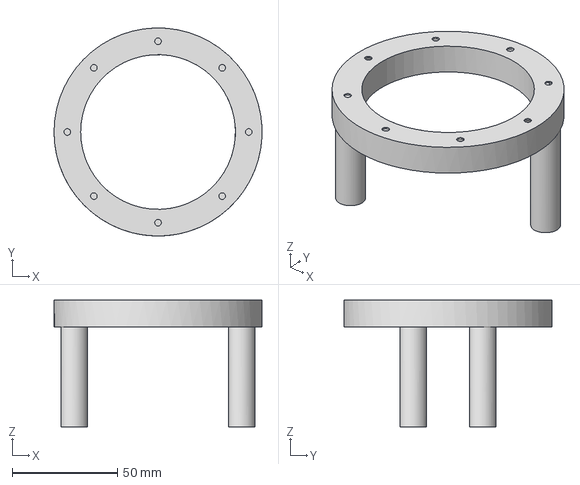
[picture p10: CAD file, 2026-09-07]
matlab/new_export/BPL-700 Assembly - injector-1__Body1.step
99.0 x 99.0 x 60.3 mm

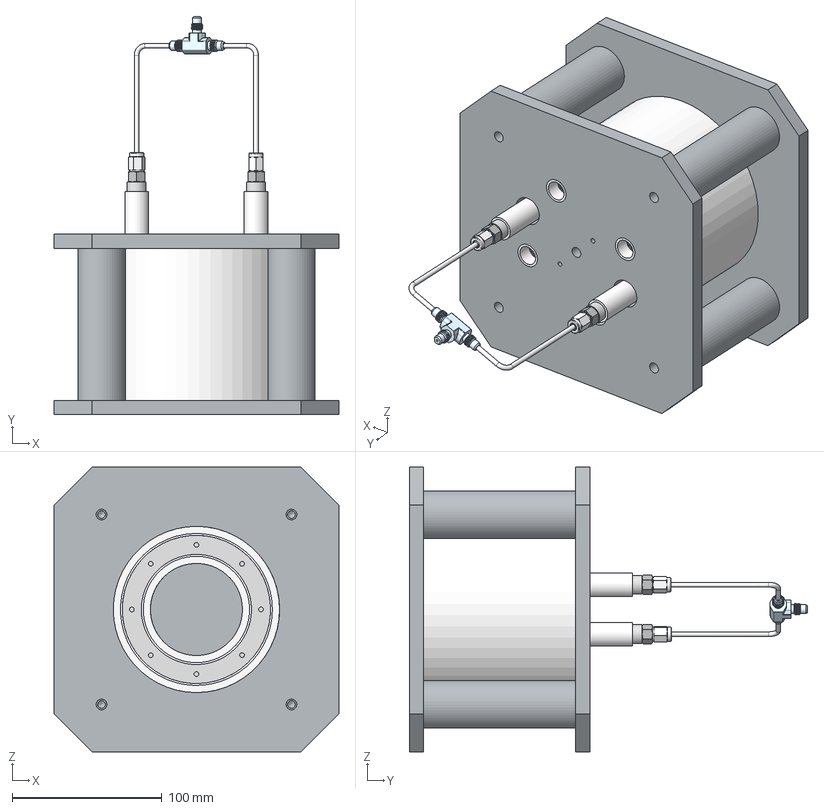
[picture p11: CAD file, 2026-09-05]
matlab/junk/BPL-700-Assembly.step
190.5 x 266.1 x 190.5 mm
CirPattern2
CirPattern1 x 4
Cut-Sweep2 x 2
Cut-Revolve1 x 2

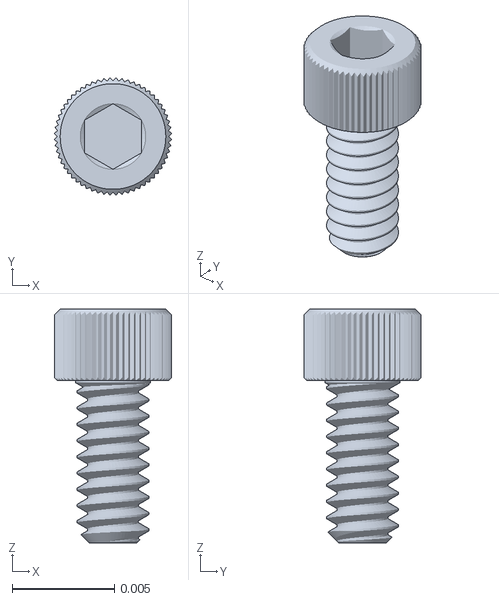
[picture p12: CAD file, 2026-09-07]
matlab/junk/stl/BPL-700 Assembly - CirPattern1.stl
0.00573 x 0.00573 x 0.0114

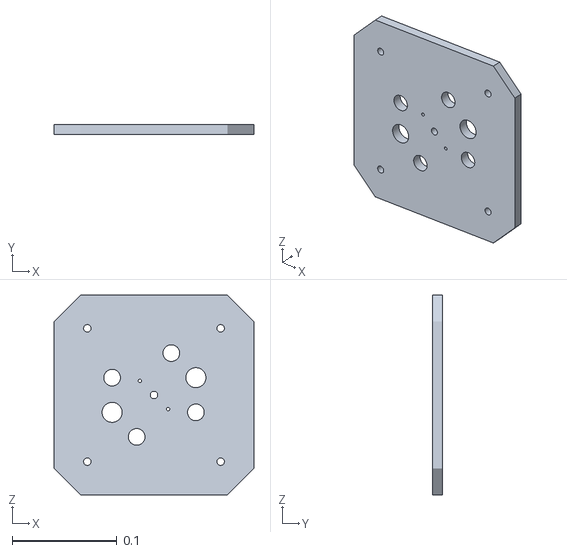
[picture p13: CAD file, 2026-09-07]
matlab/junk/stl/BPL-700 Assembly - Part 1.stl
0.191 x 0.00953 x 0.191

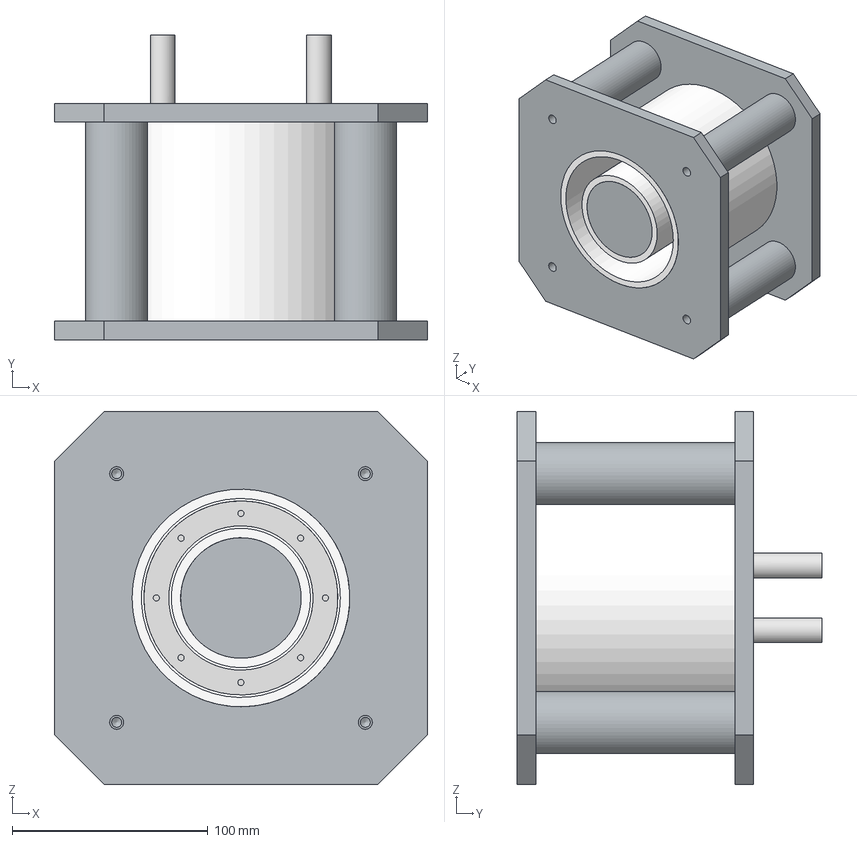
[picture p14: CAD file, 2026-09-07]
matlab/BPL-700-assem-SIMS-V1.step
190.5 x 155.6 x 190.5 mm
outer_solenoid:1__Body1 x 4
center_solenoid:1__Body1
injector:1__Body1
chamber:1__Body1
bottom_plate:1__Body1
top_plate:1__Body1

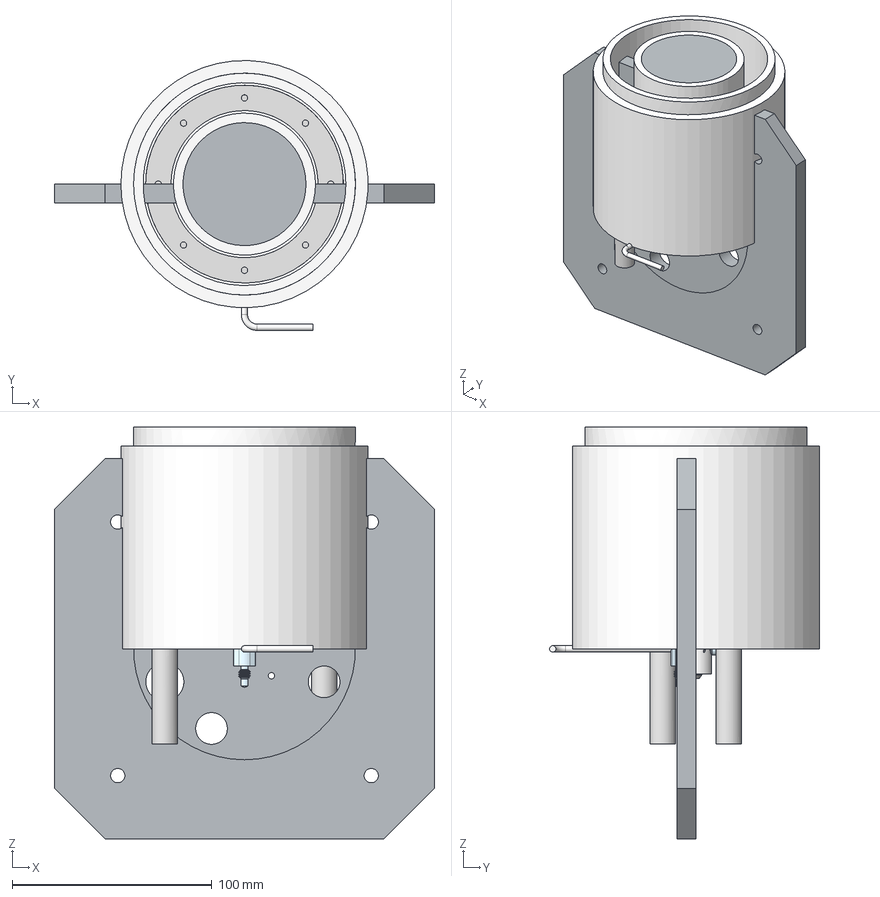
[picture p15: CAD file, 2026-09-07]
matlab/junk/BPL-700-sims-assem-203_fixed.step
190.5 x 135.2 x 206.4 mm
CirPattern2
CirPattern1 x 4
Cut-Sweep2 x 2
Cut-Revolve1 x 2

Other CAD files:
matlab/junk/BPL-700-sims-assem.step
matlab/junk/BPL-700-sims-assem-203.step
matlab/junk/BPL-700-sims-assem-203_clean.step
matlab/junk/BPL-700-part-chamber_fixed.step
matlab/junk/BPL-700-assem-203.step
matlab/junk/BPL-700-part-chamber.step
matlab/junk/BPL-700-part-chamber_clean.step
matlab/junk/BPL-700-part-injector.step
matlab/junk/BPL-700-sims-assem_clean.step
matlab/junk/BPL-700-sims-assem_fixed.step
matlab/junk/stl/BPL-700 Assembly - Part 1 (1).stl
matlab/junk/stl/BPL-700 Assembly - Part 1 (2).stl
matlab/junk/stl/BPL-700 Assembly - Part 1 (3).stl
matlab/junk/stl/BPL-700 Assembly - Part 1 (4).stl
matlab/junk/stl/BPL-700 Assembly - Part 1 (5).stl
matlab/junk/stl/BPL-700 Assembly - Part 1 (6).stl
matlab/junk/stl/BPL-700 Assembly - Part 1 (7).stl
matlab/junk/stl/BPL-700 Assembly - Part 1 (8).stl
matlab/new_export/BPL-700 Assembly - outer_solenoid-1__Body1 (1).step
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

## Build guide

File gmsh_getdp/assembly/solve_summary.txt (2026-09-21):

BPL-700 real-CAD magnetostatics solve summary
(nonlinear iron, generic soft-steel B-H curve -- see generate_regions.py)

Iron elements: 212311
  max |B|    = 1.0225 T
  mean |B|   = 0.0971 T
  median |B| = 0.0734 T
  p90 |B|    = 0.1735 T
  p99 |B|    = 0.4298 T

Overall (iron+air+windings) elements: 589708
  max |B| = 1.0225 T

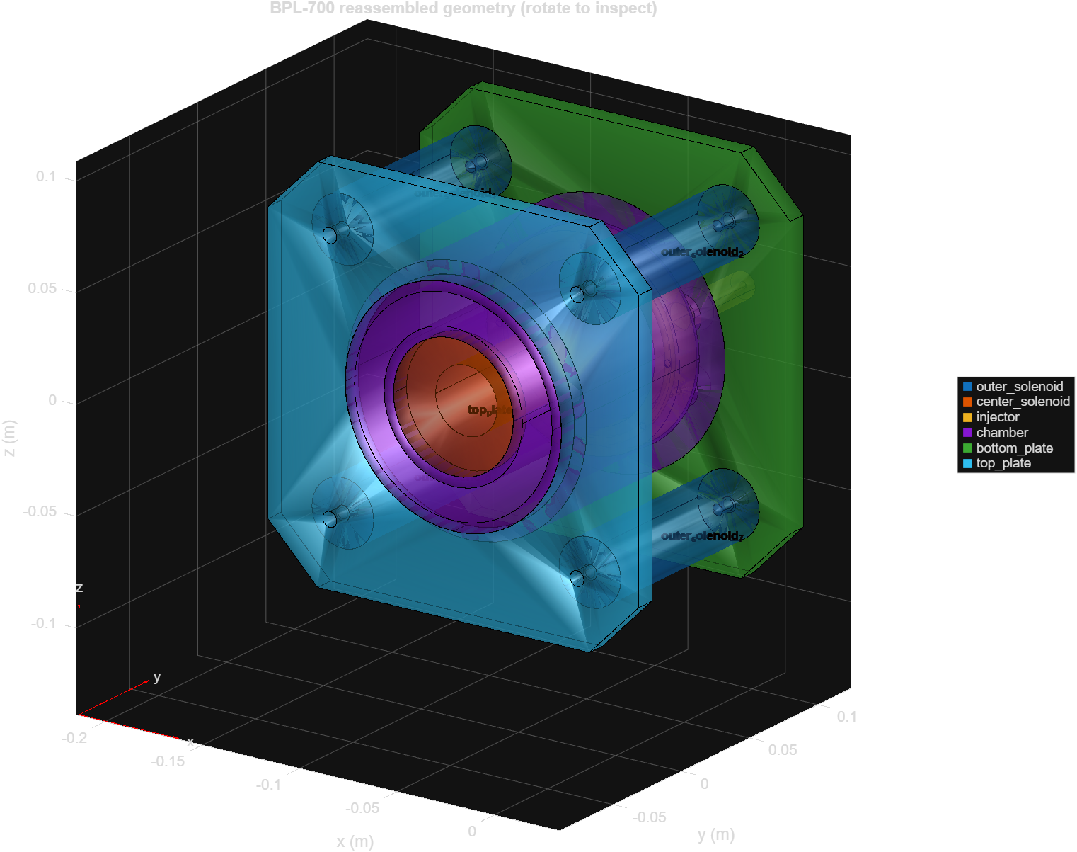
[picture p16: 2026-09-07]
matlab/junk/assembly_view.png

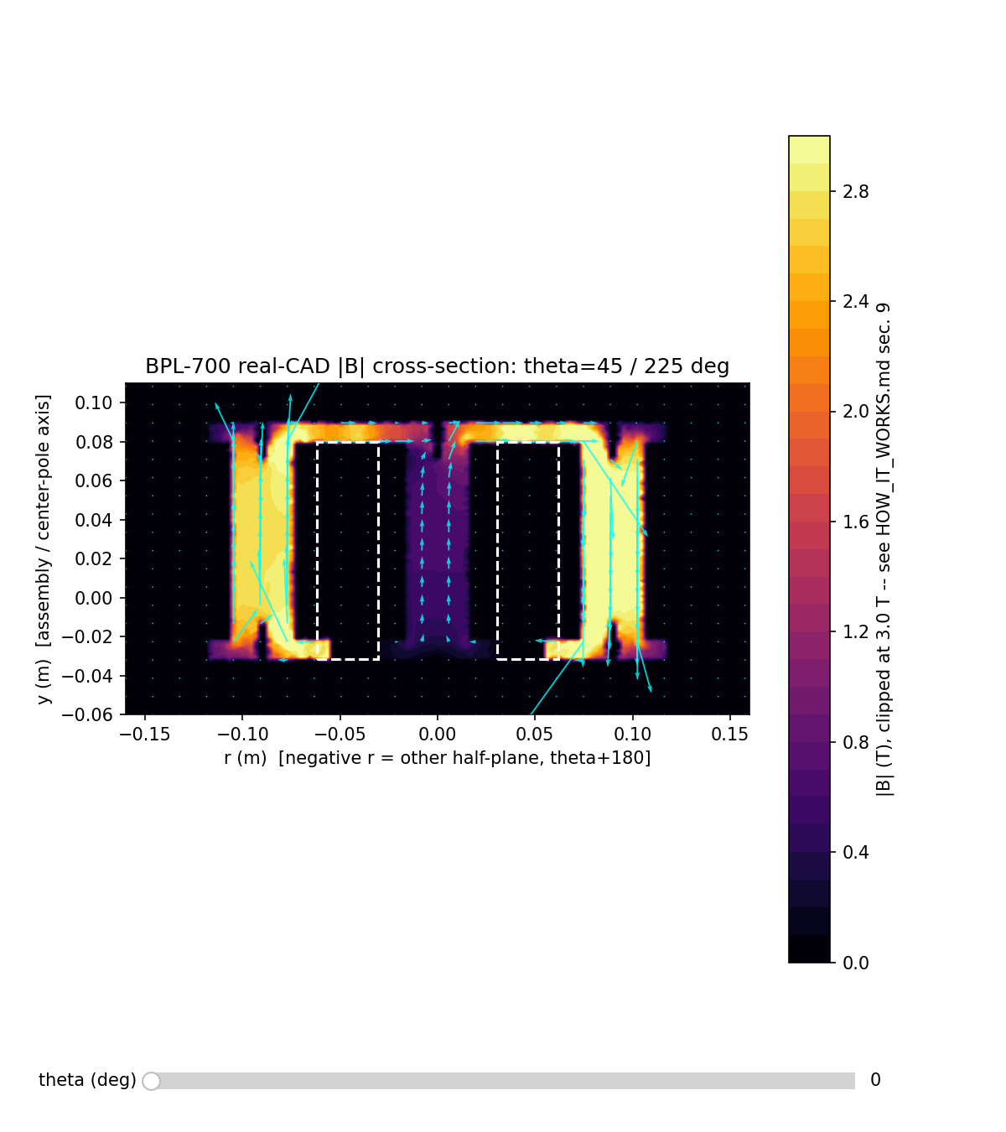
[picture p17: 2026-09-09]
gmsh_getdp/assembly/cross_section_demo_theta45.png

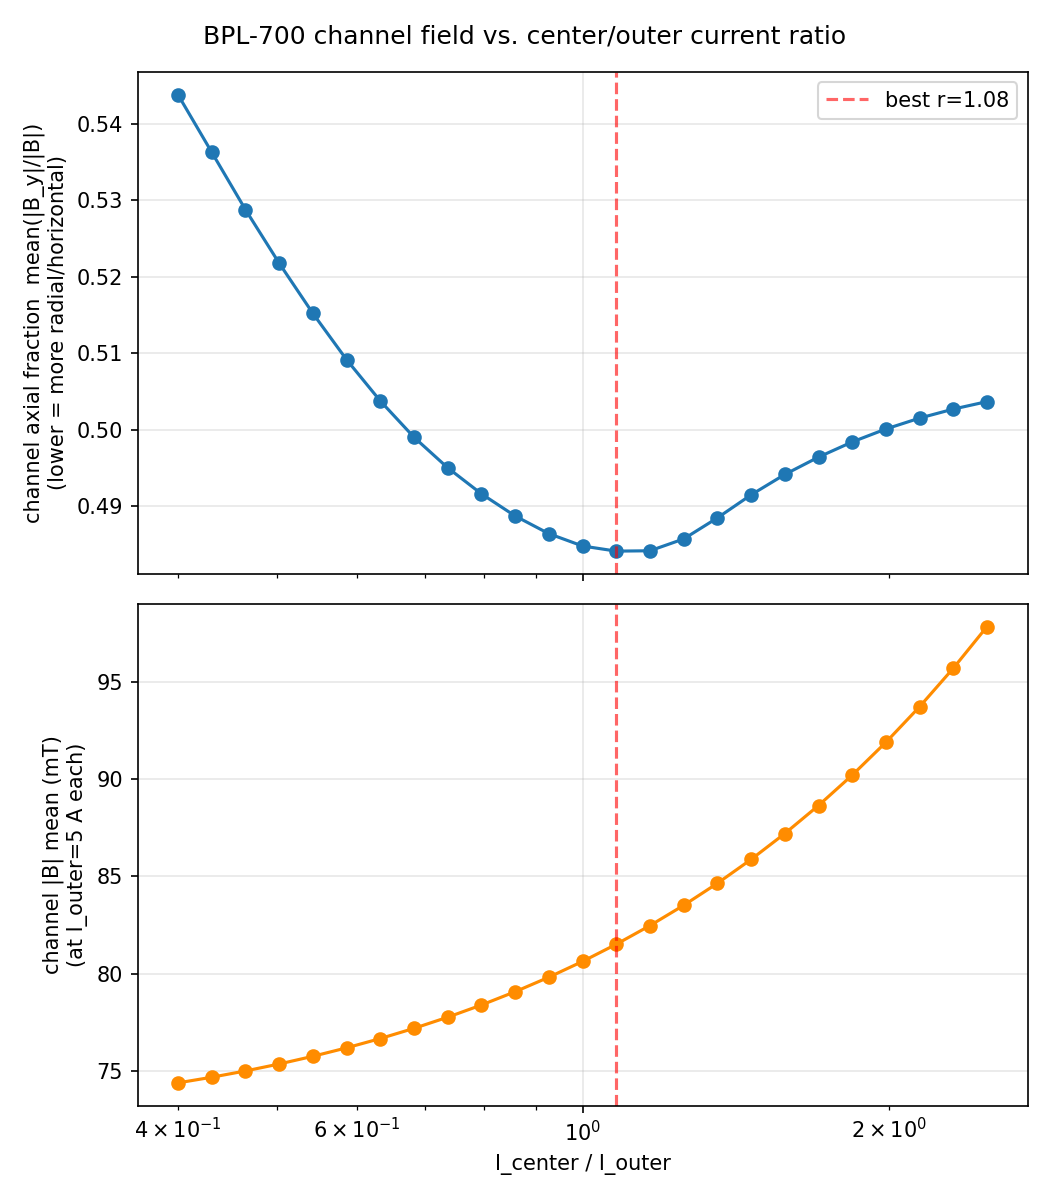
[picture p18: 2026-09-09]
gmsh_getdp/assembly/sweep_ratio.png

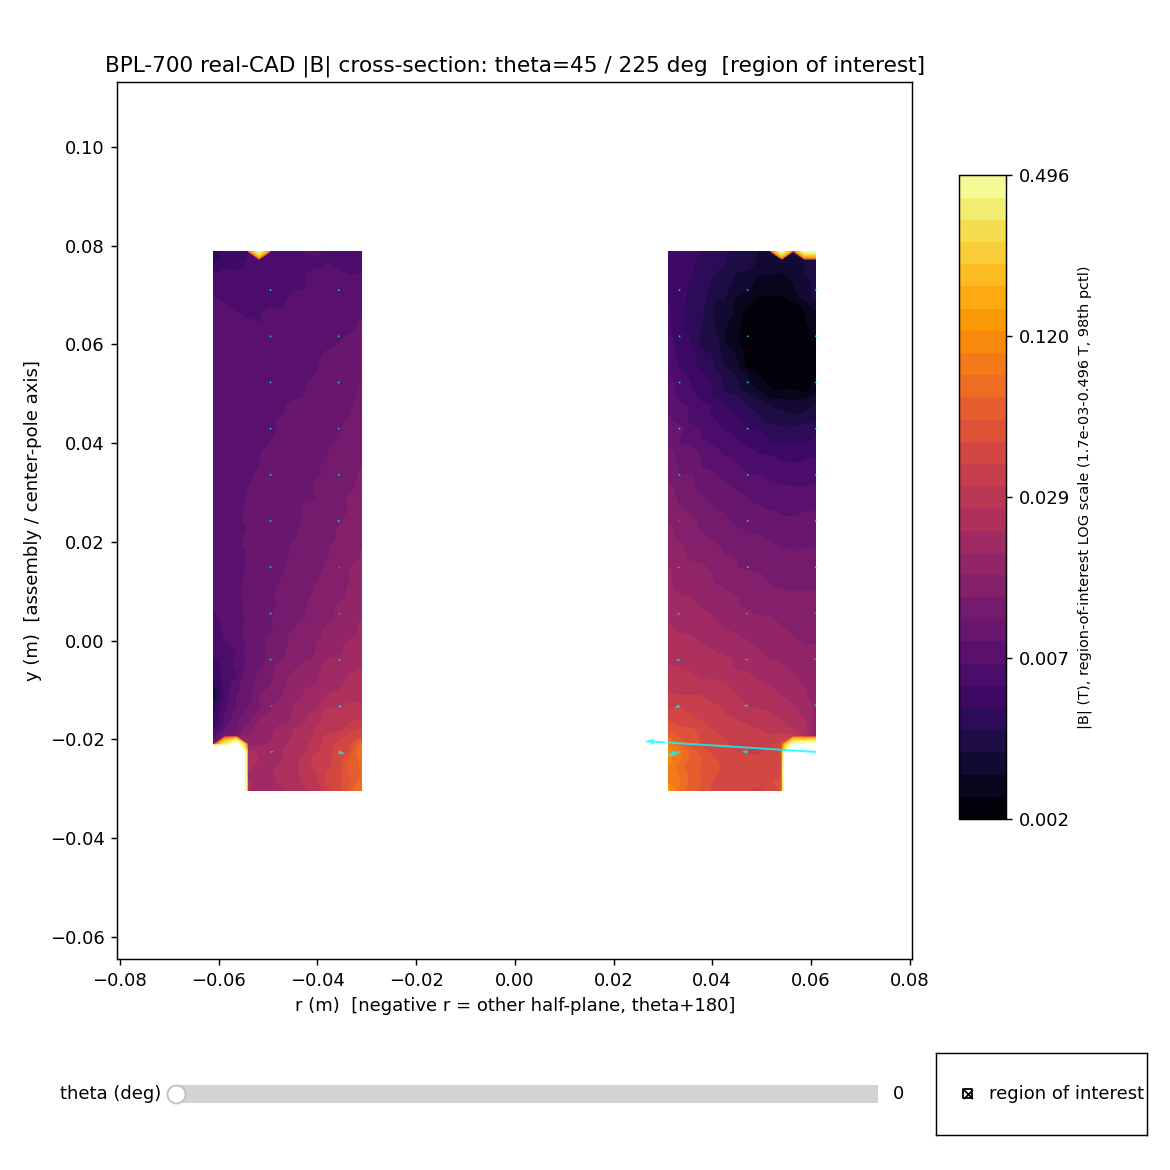
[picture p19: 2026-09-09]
gmsh_getdp/assembly/cross_section_roi_demo.png

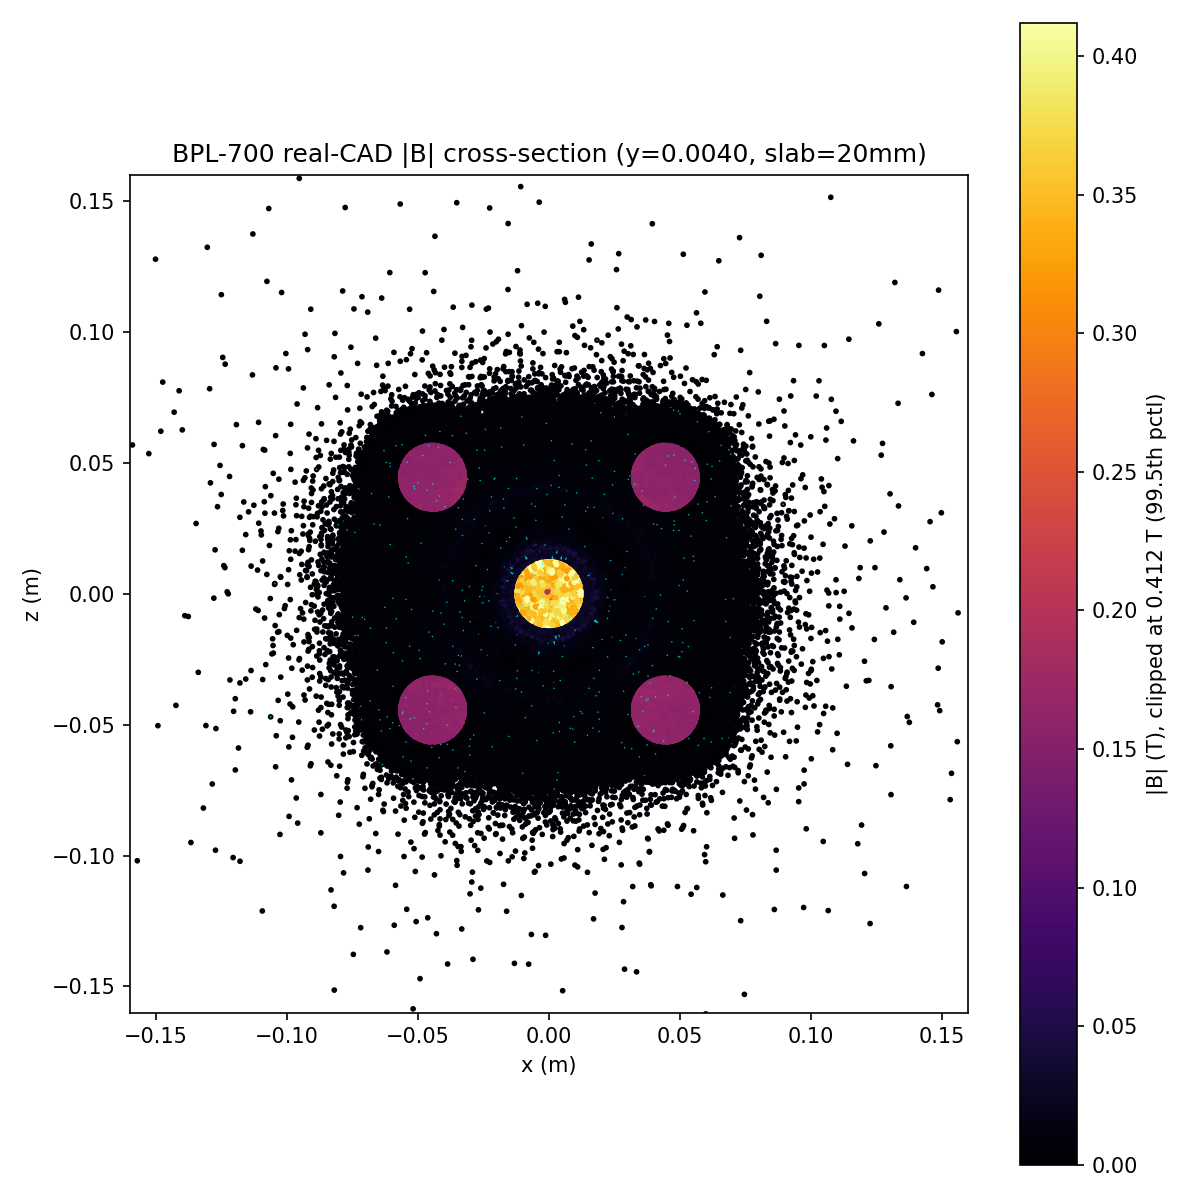
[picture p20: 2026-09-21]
gmsh_getdp/assembly/cross_section.png

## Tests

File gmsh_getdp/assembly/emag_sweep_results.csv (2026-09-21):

tag | emag_height_in | spacer_in | inner_core_dia_in | outer_coil_od_in | base_inner_At | base_outer_At | B_exit_G_at_base | scale_to_target | req_inner_At | req_outer_At | B_peak_G | y_peak_mm | B_anode_G | radial_purity_pct | shape_rmse_pct | monotonic_violation_pct | quality_score | inner_shaft_B_max_T | inner_shaft_B_mid_T | outer_shaft_B_max_T | iron_B_p99_T | iron_B_p999_T | iron_B_max_T | envelope_area_m2 | n_channel_elems | min_station_count | linear_valid | build_s | solve_s | iron_mur
h1.125_ci0.750_oo1.500 | 1.125 | 0.0 | 0.75 | 1.5 | 338.0 | 214.5 | 303.94425643212776 | 0.987023092726187 | 333.6138053414512 | 211.7164533897671 | 317.1318125869395 | -27.384375000000002 | 18.845939321123428 | 94.92105906242149 | 22.927694343491453 | 5.710604195646492 | 89.34108702227854 | 0.6146758695837851 | 0.5493560336823072 | 0.1928378349572096 | 0.5844076842686207 | 0.6824890587623675 | 1.0509762940955012 | 0.06005268520676948 | 18632 | 630 | True | 24.2 | 64.0 | 1500.0
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

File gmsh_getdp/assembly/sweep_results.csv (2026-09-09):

ratio | I_center | I_outer | axial_frac_mean | Bmag_mean | Bmag_median | Bmag_p90
0.4 | 2 | 5 | 0.54375 | 0.0743762 | 0.0045351 | 0.0150481
0.4317 | 2.1585 | 5 | 0.536256 | 0.0746657 | 0.00470421 | 0.0159834
0.466 | 2.33 | 5 | 0.528754 | 0.0749892 | 0.00489728 | 0.0169566
0.503 | 2.515 | 5 | 0.521756 | 0.0753474 | 0.00511569 | 0.0180691
0.5429 | 2.7145 | 5 | 0.515204 | 0.0757427 | 0.00536568 | 0.0192788
0.586 | 2.93 | 5 | 0.509152 | 0.0761782 | 0.00564219 | 0.0205689
0.6325 | 3.1625 | 5 | 0.503767 | 0.0766566 | 0.00593092 | 0.0219417
0.6826 | 3.413 | 5 | 0.499033 | 0.0771801 | 0.00624706 | 0.0234549
0.7368 | 3.684 | 5 | 0.49504 | 0.0777544 | 0.00659443 | 0.0251122
0.7953 | 3.9765 | 5 | 0.491638 | 0.0783818 | 0.00700016 | 0.0269372
0.8584 | 4.292 | 5 | 0.488747 | 0.079066 | 0.00746461 | 0.0288703
0.9265 | 4.6325 | 5 | 0.486438 | 0.0798115 | 0.00798019 | 0.0310001
1 | 5 | 5 | 0.484826 | 0.0806232 | 0.00853425 | 0.0333196
1.0793 | 5.3965 | 5 | 0.484157 | 0.081506 | 0.0091457 | 0.0358279
1.165 | 5.825 | 5 | 0.484204 | 0.0824668 | 0.00980993 | 0.038571
1.2574 | 6.287 | 5 | 0.485748 | 0.0835094 | 0.0105397 | 0.0414548
1.3572 | 6.786 | 5 | 0.488498 | 0.084642 | 0.0113412 | 0.0445821
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

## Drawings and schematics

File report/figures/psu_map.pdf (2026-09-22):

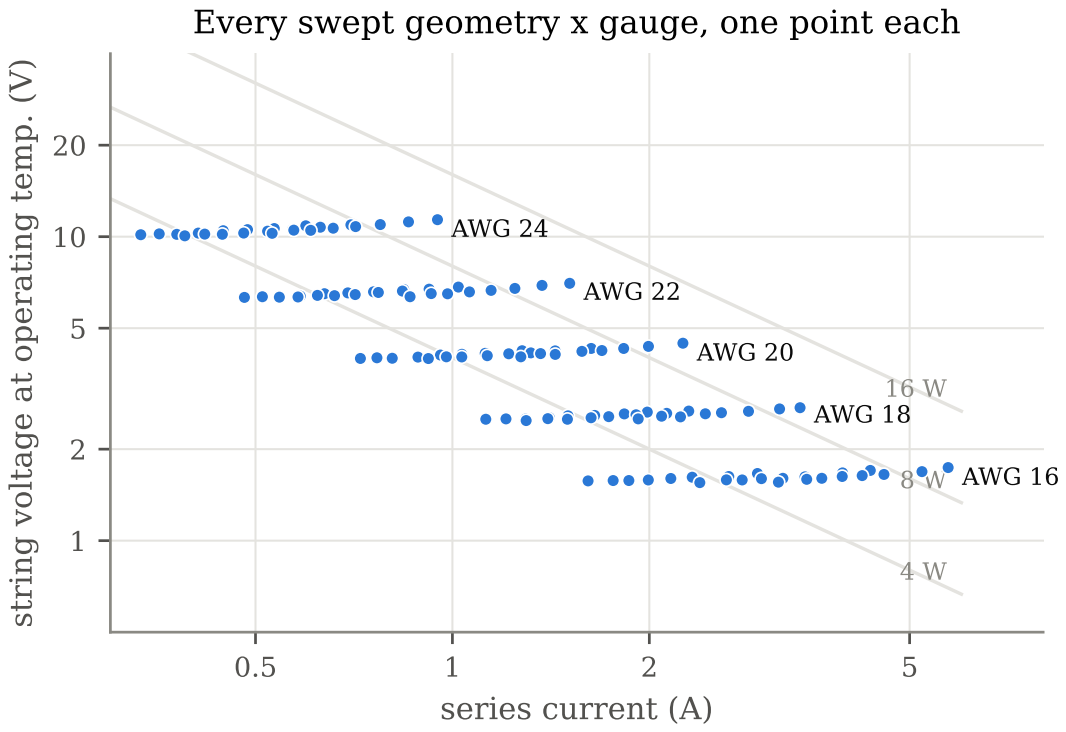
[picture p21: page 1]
series current (A); AWG 16

Every swept geometry x gauge, one point each

string voltage at operating temp. (V)

AWG 24

AWG | 22

AWG 20 16 W AWG 18

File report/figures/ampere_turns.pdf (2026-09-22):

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

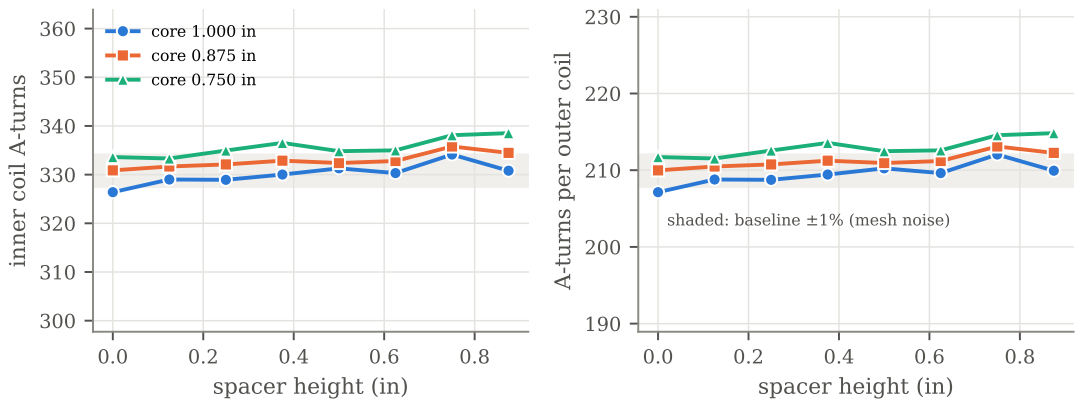
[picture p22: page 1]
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

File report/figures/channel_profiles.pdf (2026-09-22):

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

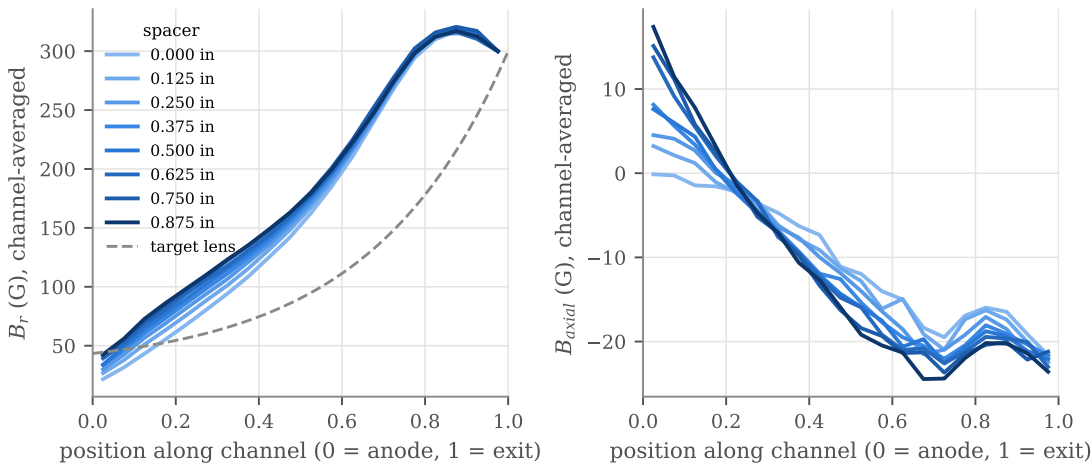
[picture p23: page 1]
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

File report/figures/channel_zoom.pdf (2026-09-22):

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

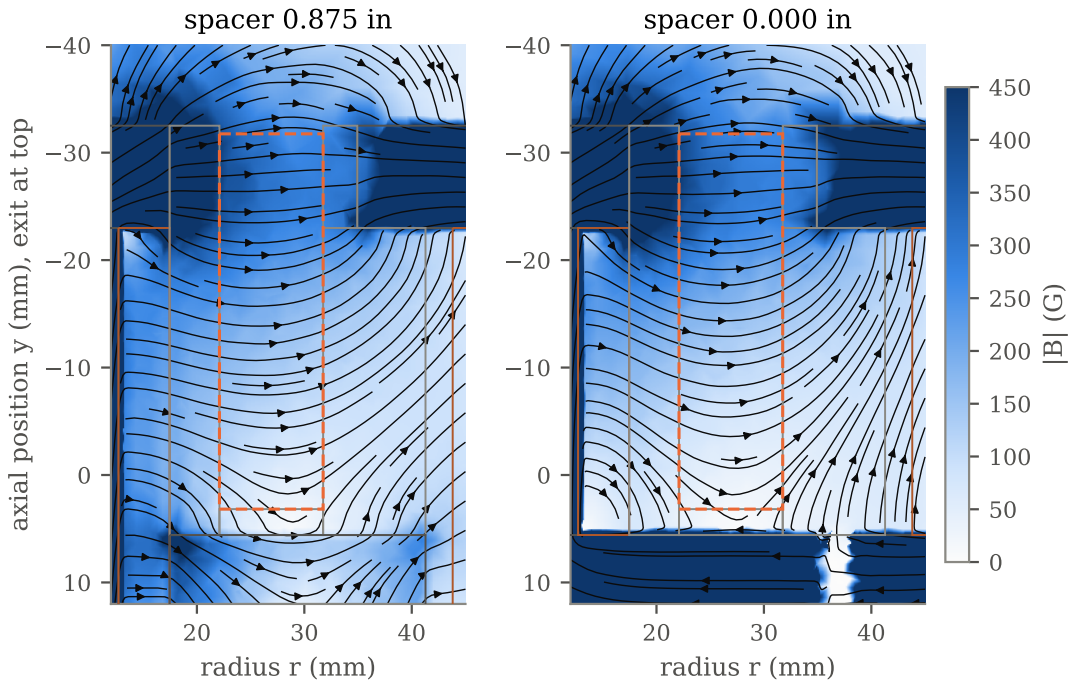
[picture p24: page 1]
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

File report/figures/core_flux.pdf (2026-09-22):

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

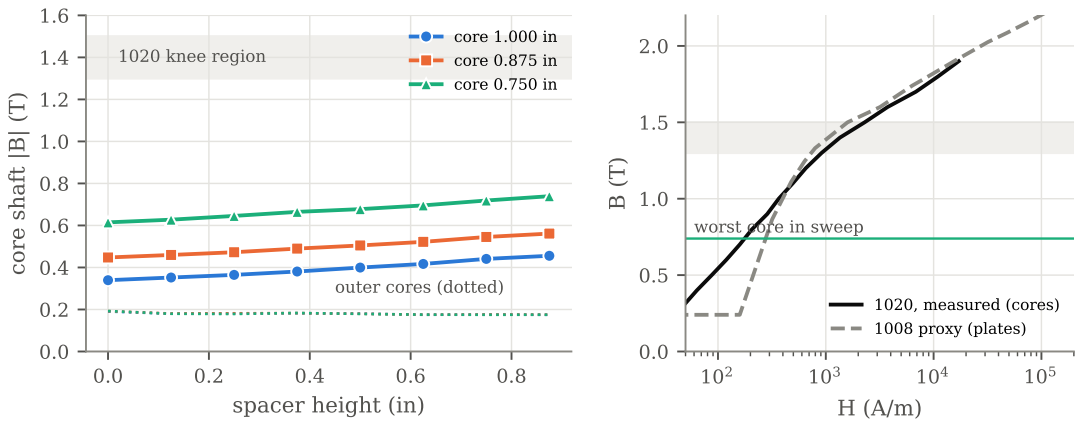
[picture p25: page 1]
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

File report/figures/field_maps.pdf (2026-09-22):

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

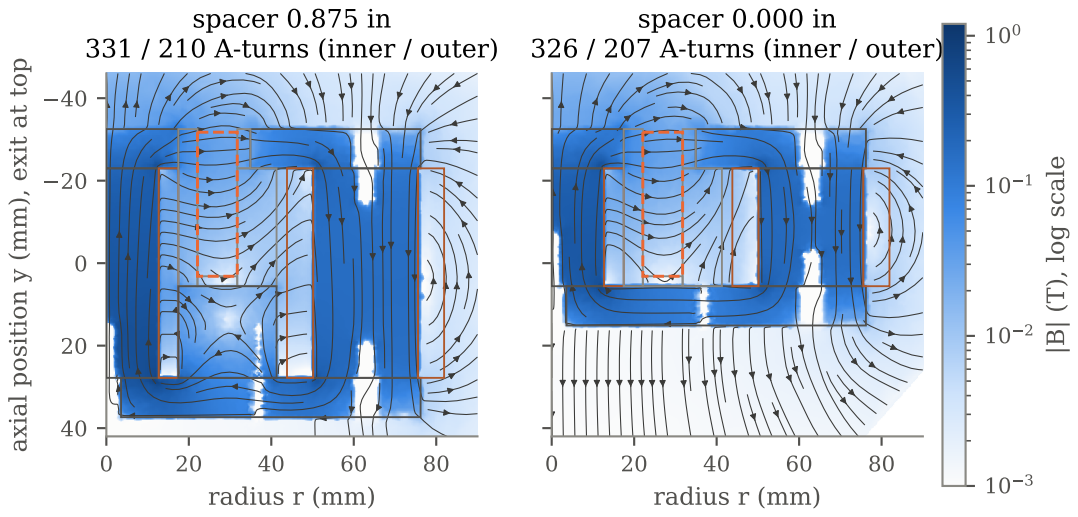
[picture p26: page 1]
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

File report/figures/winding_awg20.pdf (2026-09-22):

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

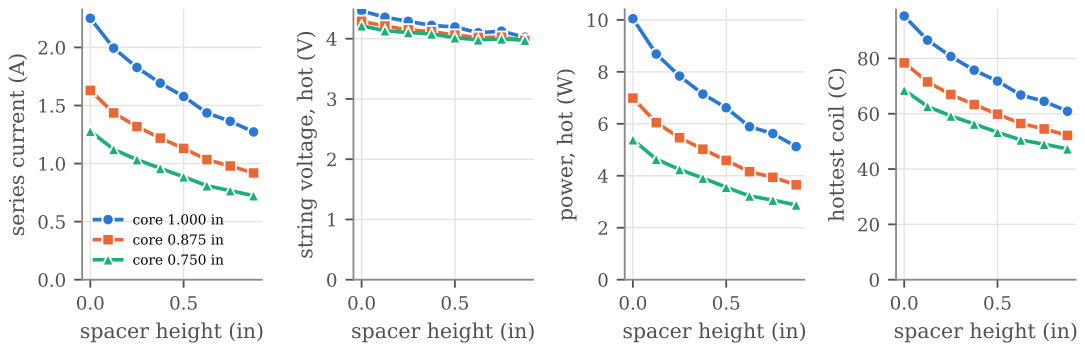
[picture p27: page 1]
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

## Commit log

2026-09-05 Minor changes
    [BPL-700-Assembly-SIMS.step, BPL-700-Assembly.step]
2026-09-07 Add real CAD geometry import pipeline and multi-domain classification prototype
    Import per-part Onshape STEP exports, reassemble with real placement
    transforms (apply_transforms.m), and visually verify the result
    (het_view_assembly.m). Prototype the union+findCell approach for
    multi-material region classification (new_export/scratch_classify.m,
    scratch_windings.m). Move superseded exports and one-off diagnostic
    scripts into junk/, and update README to reflect current status.
    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
    [BPL-700 Assembly - CirPattern1.stl, BPL-700 Assembly - CirPattern2.stl, BPL-700 Assembly - Cut-Revolve1.stl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]
2026-09-07 Document center-winding sizing and the union() sliver-face blocker
    Record the chamber-bore profiling result that sized the center winding
    (thin-section gap, no invented wall thickness), confirm the 5-winding
    geometry stage is collision-free, and capture the union() geometry-kernel
    limitation found unioning chamber into the iron blob (sliver faces,
    unmeshable at any Hmax/Hmin) along with the proposed clearance-gap fix
    that's still awaiting a decision.
    Claude-Session: https://claude.ai/code/session_01Vrz463tKhV4W5PRcrrZUyC
2026-09-08 Diagnose union blocker to specific interfaces, add pairwise/tessellation checkers
    Re-ran the documented iron+chamber union blocker on this machine and
    found it doesn't reproduce as described: the iron-only union now fails
    outright before chamber is even involved. Isolating every one of the
    assembly's 9 real touching interfaces individually (new
    scratch_pairwise_diagnose.m) shows 5 are broken, not 1 - including all
    3 of chamber's contacts and 2 of 4 outer-pole-to-top-plate mates. The
    broken pole mates correlate with a longer Onshape mate chain in the
    placement transform table, not part shape; injector's own STEP
    tessellation is separately dirty (scratch_check_tessellation.m).
    Documented both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
2026-09-09 Add Gmsh/GetDP magnetostatics pipeline, current-ratio sweep, and winding specs
    Second independent FEM pipeline (Gmsh geometry/meshing + GetDP solve)
    for the BPL-700 assembly, since MATLAB's fegeometry.union() couldn't
    cleanly fuse 5 of 9 real touching interfaces. Fuses all 7 iron parts
    on the first try and includes a validated toy-solenoid check (1.4%
    vs. analytic).
    Also documents current_sweep.py's center/outer current-ratio sweep
    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
    [assembly_params.txt, sweep_results.csv, toy_params.txt]
2026-09-18 Add Onshape API automation, field-quality metric, and repo-level README
    Onshape HMAC auth + caching STEP-pull (emag_height-parametrized) lays
    the groundwork for a geometry sweep; field_quality.py gives that sweep
    a scoring metric for the channel B-field shape. Also adds a
    whole-assembly STEP import spike and a top-level README mapping the
    repo now that two independent FEM pipelines exist side by side.
2026-09-18 Switch to whole-assembly Onshape STEP ingestion, add nonlinear iron B-H curve
    Sends all 5 real Onshape Configuration parameters (emag_height,
    inner/outer_coil_id/od) through get_step_for_config instead of just
    emag_height -- the coil ID/OD params size real coil solids and their
    soft-iron cores in the CAD, not local-only resizes as previously assumed.
    build_assembly.py now imports the whole-assembly STEP directly (14 named
    bodies), fuses iron incrementally, and uses the real coil geometry instead
    of Gmsh-built primitives, retiring the old per-part-STEP + hardcoded-
    TRANSFORMS pipeline. Found and worked around a real OCC bug along the way
    (getBoundingBox() is loose on curved STEP-imported soli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
    [assembly_params.txt]
2026-09-18 Retune nonlinear iron load-stepping after first attempt diverged
    First 8-stage ramp (NL_iter_max=20, NL_tol_rel=1e-6) ran to completion
    but didn't converge: the 50% stage was still improving monotonically when
    it hit the iteration cap, and the next stage inherited that unconverged
    field and diverged explosively. Root cause was iteration/tolerance
    budget, not the method.
    Retuned to a finer 16-stage non-uniform ramp (denser above 40%),
    NL_iter_max=60, NL_tol_rel relaxed to 1e-4. Second attempt converged
    cleanly through stage 3 (40%, no oscillation) but was killed by the
    environment's low-memory protection partway into stage 4 -- host memory
    pressure from repeated large sparse solves, not a so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
2026-09-20 Size excitation to the 300 G channel target, fixing nonlinear convergence
    The 5 A excitation was inherited from the old MATLAB parametric check, not
    derived from a design target. A lumped reluctance check against the 300 G
    channel-exit goal needs only ~450-900 A-turns versus the 2500 being applied,
    and 5 A drove peak iron to 2.16 T -- past the B-H knee, which is the sole
    reason the solve needed 16-stage load-stepping and still failed (~1 hr,
    non-convergent, killed by host memory pressure).
    At 2 A peak iron is 0.859 T, the iron stays effectively linear, and the same
    solve converges in 11 Picard iterations / 19.6 min / 805 MB with a 2-stage
    ramp. Measured channel field is 292 G at the exit pl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
    [assembly_params.txt]
2026-09-20 Fix winding current-density area; derive a real winding design
    Both build_assembly.py and build_toy.py computed the winding's
    current-density area as the annulus pi*(ro^2-ri^2). The current is
    azimuthal, so it crosses a plane CONTAINING the axis and the correct area
    is the coil's r-z section (radial thickness x height); the annulus is the
    area for axial flow. It is 1.84x (inner) / 1.94x (outer) too large on
    these coils and 2.75x on the toy, so every solve silently applied about
    half its nameplate ampere-turns.
    The toy validation could not catch this: build_toy.py fed the same wrong
    area into both the FEM source term and its analytic reference, so the two
    agreed to 1.4% at 10.19 mT while the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
    [assembly_params.txt, toy_params.txt]
2026-09-20 Add magnets-only steady-state thermal model
    Answers whether anything gets hot from energising the magnets alone,
    before any plasma interaction is considered. Vacuum, radiation-only heat
    path, no conduction to a mount: every watt leaves by radiation from the
    outer envelope, so the result is a near-pure radiation balance.
    At the 1.25 A design point the assembly settles at 61 C dissipating
    5.3 W, with the coils 1 K above the iron if bonded to the core and 25 K
    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
2026-09-21 Specify iron as ASTM A36, add MATERIALS.md with sourced properties
    The pole and plate material is now pinned to what will actually be bought:
    SendCutSend hot-rolled pickled-and-oiled A36/A1018. Their other mild steel
    (1008 cold rolled) only goes to 0.135in, too thin for anything in this
    assembly; A36 runs .187-.500in and is stocked at exactly the 0.375in plate
    thickness, so each plate is a single laser-cut piece rather than a
    laminated stack. The cores are round turned parts and still need bar stock
    from elsewhere, which means they are a separate grade decision -- and they
    carry the highest flux density in the circuit.
    The B-H curve is AISI 1008 data used as a PROXY for A36 and is
    deliberat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
2026-09-21 Size the chamber spacer: emag_height sweep, winding design, EMAG report
    Sweeps emag_height (spacer = emag_height - 1.125 in, 0 to 0.875 in) against
    inner core diameter (1.000/0.875/0.750 in), 25 full-3D linear-iron solves,
    each scaled to 300 G at the channel exit. Result: the spacer barely moves the
    A-turns needed (326-339 inner across the grid, ~1% = mesh noise); it mostly
    sets winding room. A thinner core buys the room back: no spacer with a 0.750 in
    core runs at 1.28 A / 5.4 W on AWG 20, vs 1.27 A / 5.1 W today. Cores stay at
    0.34-0.74 T, below the 1.3-1.5 T knee.
    - gmsh_getdp/assembly/emag_sweep.py: resumable Onshape -> mesh -> linear solve
    -> metrics driver; --validate (+1.25% vs com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
    [emag_sweep_results.csv]
2026-09-22 Try a finer nonlinear ramp on the worst-case core; add residual watchdog
    Re-ran the nonlinear check on the highest-core-flux sweep point (0.750 in
    core, 0.875 in spacer) with a 9-stage load ramp (0.5..1.0) instead of 2.
    Stages converged at 50/60/70% (9, 16, 35 Picard iterations) but contraction
    fell every stage (~2.3x -> 1.7x -> 1.2x per iteration) and hit ~1.1x at 75%,
    projecting past the 60-iteration cap, while getdp.exe grew to 13 GB. Killed
    under the watchdog criteria. Difficulty rises with current level, not step
    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
2026-09-30 Specify a real magnet wire and a two-channel supply
    The winding design was sized around "AWG 20 single-glass-served, 200 C"
    wire with estimated insulated diameters. That product cannot be bought:
    - NEMA MW 1000 tabulates round polyester-glass served wire from 1/0 down
    to AWG 12 and no finer. Glass serving is filaments, whose thickness
    does not scale with the conductor, so it adds ~0.15-0.21 mm to the OD
    at any gauge and stops being offered on fine wire.
    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
2026-10-03 Retarget to BPL-1000 and add the electromagnet sizing sweep
    The CAD moved to a new Onshape document (BPL-1000: longer chamber, renamed
    bodies, and a parameter set that separates core diameter from winding
    build). This finishes that retarget and builds the sizing tooling on it.
    Retarget:
    - onshape/cache.py: new DID/WID/EID, six parameters with declared ranges
    (out-of-range values are rejected, since Onshape clamps silently), and a
    cache key that includes the document and element.
    - build_assembly.py: BPL-1000 body names; coil pole and radii taken from the
    geometry. Small holes in the iron (bolt clearances, tapped core ends, 2 mm
    lead holes) are filled by OCC defeaturing; resolving th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
2026-10-04 Run the BPL-1000 electromagnet sizing sweep on a frozen CAD copy
    All 35 geometries (18 inner, 16 outer, 4 plate-thickness, sharing one
    baseline) were solved on one microversion of an Onshape copy that nobody
    edits. The original document was being edited mid-sweep, which broke two
    runs and mixed CAD versions in the results.
    - onshape/cache.py: point at the frozen copy; record each pull's
    microversion so every result traces to an exact CAD state.
    - onshape/client.py: retry 429s at send(), so each attempt is re-signed
    with a fresh nonce. Fail fast when Retry-After shows a used-up quota
    window (seen: 6975 s) instead of retrying inside it.
    - build_assembly.py: unrecognised bodies are treat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
2026-10-06 Specify the BPL-1000 electromagnets: AWG 20, 0.75 in cores
    Final design chosen with the user: AWG 20 heavy-build polyimide and 0.75 in
    cores for all five magnets (one bar stock). Inner coil: 230 turns (5 x 46)
    at 1.53 A. Outer coils: 4 x 184 turns (4 x 46) in series at 1.21 A. Both
    channels sit in the requested 1-2 A band; 4.4 W total, iron at ~58 C.
    Ampere-turns come from a combined solve of exactly this geometry:
    352 / 223 at the committed ratio, cores at 0.66 / 0.32 T.
    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
2026-10-06 Add B-field cross-section figures; plot sweeps at the committed ratio
    field_cross_sections.py solves the baseline and final geometries at their
    operating excitation and renders r-y slices plus the channel B_r profile
    against the field-quality target. em_sizing_plots.py now plots the
    committed 214.5/338 ratio throughout, excludes the plate points from the
    outer family, and draws coil power vs overall diameter per gauge.
2026-10-06 Nonlinear check of the electromagnet spec via Newton-Raphson
    Picard was converging but far too slowly: about 4 of 9 load stages in 2 hours.
    Add an opt-in Newton path (-setnumber Newton 1):
    - B-H tangent as a JacNL term. GetDP 3.5 segfaults on a plain Generate
    whenever the formulation holds a JacNL term, so the Newton path
    assembles only through GenerateJac/SolveJac inside IterativeLoop.
    - Akima interpolation of the B-H curve (continuous tangent) plus a
    mu0 saturation tail past the last table point.
    - A 0.5/0.8/0.9/1.0 load ramp, and NL_relax for step damping.
    The Picard path is unchanged.
    Result for the final design: the nonlinear exit field reads 0.73% below
    linear at 90% of spec cur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
2026-10-21 Add 2-D axisymmetric field-shaping suite and study
    Axisymmetric gmsh/GetDP model of the BPL-1000 magnetic circuit, calibrated
    against the 3-D solve, plus the pole-tip, trim-coil and shaping studies
    (coil placement, rear gaps, plate thickness, magnetic screens) and their
    report. Run cache is ignored.
2026-10-21 Optimise the field-shaping features in 2-D (no cap lip)
    One-at-a-time sweeps of the front-plate and pole-cap tapers and the inner
    and outer screens, a compass search and a +-0.5 mm tolerance check, all at
    the spec ratio and 300 G peak. Every run records the channel shape, coil
    drive and per-part iron |B| / saturation ratio (flux-corrected posts).
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2026-10-29 het: iron swappable through params.iron; permeability and Design A search studies; README
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2026-10-29 pic: 3-D vacuum electrostatics, Design B magnet map for WarpX, 2-D PIC model (WIP), assumptions report
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
